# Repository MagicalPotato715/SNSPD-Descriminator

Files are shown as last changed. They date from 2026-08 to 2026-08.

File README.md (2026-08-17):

IMPORTANT INFO:
-
- CTD is the Constant Threshold Discriminator, and contains two amplifiers and one comparator.
- Compute contains a Teensy 4.1 MCU (for counting and general control purposes) and DAC60501MDGSR DAC for CTD reference voltage.
- The single board with both CTD and compute, while possible to manufacture, is not recommended due to general price spiking over 10x10cm
- There may be slight physical mismatches between corresponding parts on CTD/compute and the single board.
- PCBA Essentials should be enough for ordering PCBA; the BOM sources from Mouser; however, most, if not all, components can be found on Digikey.
- When ordering PCBA for the compute board, make sure to separately order Teensy 4.1 boards with header pins already attached (or attach them yourself).
- 

Logistics:
- 
- ***Compute DAC may not Function Correctly***: In this case, J8 (bottom left corner) is hardware controlled through a voltage divider and the 200 ohm trim.
- ***Scalability***: Although the current compute board only features 6 JST conns, the Teensy 4.1 allows this to be expandable to ~30.
- ***CTD Hardware Troubleshooting***: The two LEDs should both light if both 3.3v and 5v respectively, are active. The test points can be used to troubleshoot signals.
- ***Ratbites on Single Board Not Snapping***: There is a chance for the ratbites to not work; the board still functions without the connection severed.
- ***Simulation***: The SPICE models in the single board folder should be enough to simulate; the models may be slightly outdated, look in "Misc files" if needed.
- ***Required Electronics***: The CTD requires a biased SNSPD pulse input via the correct coaxial cable; CTD and compute need to be connected by a 1x5 male-male JST wire with 2.5mm pitch; the compute board requires an external stable 5v source via coaxial cable; the CTD cannot function without 5v coaxial cable power.

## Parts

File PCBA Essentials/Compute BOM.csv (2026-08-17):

Reference | Qty | Value | Footprint | Manufacturer | MPN | Mouser PN | Datasheet
A1 | 2 | Conn_01x24_Socket | Connector_PinSocket_2.54mm:PinSocket_1x24_P2.54mm_Vertical | Samtec | SSQ-124-01-G-S | 200-SSQ12401GS | https://www.sullinscorp.com/
C16,C18,C20 | 3 | 0.1uf | Capacitor_SMD:C_0603_1608Metric | Samsung Electro-Mechanics | CL10B104KB8NNNC | 187-CL10B104KB8NNNC | ~
C17,C19 | 2 | 1uf | Capacitor_SMD:C_0603_1608Metric | Samsung Electro-Mechanics | CL10A105KO8NNNC | 187-CL10A105KO8NNNC | ~
D_1,D_2,D_3,D_4,D_5,D_6 | 6 | LED | LED_SMD:LED_0603_1608Metric | Lite-On | LTST-C190KRKT | LTST-C190KRKT | ~
J2,J4,J5,J6,J7,J8 | 6 | Conn_01x05_Socket | Connector_JST:JST_XH_B5B-XH-A_1x05_P2.50mm_Vertical | JST | B5B-XH-A | 306-B5B-XH-A-GU | ~
J_Power1 | 1 | Conn_Coaxial | Connector_Coaxial:SMA_Samtec_SMA-J-P-H-ST-EM1_EdgeMount | Samtec | SMA-J-P-H-ST-EM1 | SMA-J-P-H-ST-EM1 | ~
R3,R13,R14 | 3 | 1k | Resistor_SMD:R_0603_1608Metric | Yageo | RC0603FR-071KL | 603-RC0603FR-071KL | ~
R4 | 1 | 4.7k | Resistor_SMD:R_0603_1608Metric | Yageo | RC0603FR-074K7L | RC0603FR-074K7L | ~
R5 | 1 | 5.6k | Resistor_SMD:R_0603_1608Metric | Yageo | RC0603FR-075K6L | 603-RC0603FR-075K6L | ~
R7,R8,R9,R10,R11,R12 | 6 | 2k | Resistor_SMD:R_0603_1608Metric | Yageo | RC0603FR-072KL | RC0603FR-072KL | ~
3386F-1-201LF | 1 | 200ohms | Potentiometer_THT:Potentiometer_Runtron_RM-065_Vertical | Bourns | 3386F-1-201LF | 3386F-1-201LF | ~
U5 | 1 | DAC60501ZDGSR | DAC60501ZDGSR:DGS10_TEX | Texas Instruments | DAC60501ZDGSR | 595-DAC60501ZDGSR | https://www.ti.com/lit/gpn/dac60501

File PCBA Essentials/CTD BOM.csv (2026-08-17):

Reference | Qty | Value | Footprint | Manufacturer | MPN | Mouser PN | Datasheet
U_Comparator1 | 1 | LTC6752HSC6-1#TRPBF | Package_TO_SOT_SMD:SOT-363_SC-70-6 | Analog Devices | LTC6752HSC6-1#TRPBF | LTC6752HSC6-1#TRMPBF | https://www.analog.com/media/en/technical-documentation/data-sheets/6752fc.pdf
U2 | 1 | PGA-103+ | Package_TO_SOT_SMD:SOT-89-3 | Mini-Circuits | PGA-103+ | 512-PGA-103+ | https://www.minicircuits.com/pdfs/PGA-103+.pdf
U1 | 1 | PSA4-5043+ | PSA4-5043+:MMM1362_MNC | Mini-Circuits | PSA4-5043+ | 712-PSA4-5043+ | https://www.minicircuits.com/pdfs/PSA4-5043+.pdf
R_Hyst1 | 1 | 80k | Resistor_SMD:R_0603_1608Metric | Yageo | RC0603FR-0780KL | 603-RC0603FR-0780KL | ~
R_b1 | 1 | 1k | Resistor_SMD:R_0603_1608Metric | Yageo | RC0603FR-071KL | 603-RC0603FR-071KL | ~
R_a1 | 1 | 5.6k | Resistor_SMD:R_0603_1608Metric | Yageo | RC0603FR-075K6L | 603-RC0603FR-075K6L | ~
Rterm1,R_s1 | 2 | 50 | Resistor_SMD:R_0402_1005Metric | Yageo | RC0402FR-0750RL | 603-RC0402FR-0750RL | ~
R1 | 1 | 150 | Resistor_SMD:R_0603_1608Metric | Yageo | RC0603FR-07150RL | 603-RC0603FR-07150RL | ~
R2 | 1 | 2k | Resistor_SMD:R_0603_1608Metric | Yageo | RC0603FR-072KL | RC0603FR-072KL | ~
R6 | 1 | 4.7k | Resistor_SMD:R_0603_1608Metric | Yageo | RC0603FR-074K7L | RC0603FR-074K7L | ~
L2 | 1 | 620nH | Inductor_SMD:L_0603_1608Metric | Murata | LQW18AN62NJ00D | 81-LQW18AN62NJ00D | ~
L1,L3 | 2 | 100nh | TCCH+:GU1604_MNC | Mini-Circuits | TCCH-80+ | 139-TCCH-80 | https://www.minicircuits.com/pdfs/TCCH-80+.pdf
J3 | 1 | Conn_Coaxial | Connector_Coaxial:SMA_Samtec_SMA-J-P-H-ST-EM1_EdgeMount | Samtec | SMA-J-P-H-ST-EM1 | 713-SMA-J-P-H-ST-EM1 | ~
C13,C15 | 2 | 1uf | Capacitor_SMD:C_0603_1608Metric | Samsung Electro-Mechanics | CL10A105KO8NNNC | 187-CL10A105KO8NNNC | ~
C10 | 1 | 0.33uf | Capacitor_SMD:C_0603_1608Metric | Yageo | CC0603KRX7R9BB334 | 603-CC0603KRX7R9BB334 | ~
C9 | 1 | 330pf | Capacitor_SMD:C_0402_1005Metric | Samsung Electro-Mechanics | CL05C331JB5NNNC | 187-CL05C331JB5NNNC | ~
C7 | 1 | 330pf | Capacitor_SMD:C_0603_1608Metric | Samsung Electro-Mechanics | CL10C331JB8NNNC | 187-CL10C331JB8NNNC | ~
C6,C11 | 2 | 10uf | Capacitor_SMD:C_0805_2012Metric | Samsung Electro-Mechanics | CL21A106KOQNNNG | 187-CL21A106KAQNNNE | ~
C5,C12,C14 | 3 | 0.1uf | Capacitor_SMD:C_0603_1608Metric | Samsung Electro-Mechanics | CL10B104KB8NNNC | 187-CL10B104KB8NNNC | ~
C3 | 1 | 100pf | Capacitor_SMD:C_0402_1005Metric | Samsung Electro-Mechanics | CL05C101JB5NNNC | 187-CL05C101JB5NNNC | ~
C1,C2,C4,C8 | 4 | 0.01uf | Capacitor_SMD:C_0402_1005Metric | Samsung Electro-Mechanics | CL05B103KB5NNNC | 187-CL05B103KB5NNNC | ~
J1 | 1 | Conn_01x05_Socket | Connector_JST:JST_XH_B5B-XH-A_1x05_P2.50mm_Vertical | JST | B5B-XH-A | 306-B5B-XH-A-GU | ~
D_Life3.3, D_Life5 | 2 | LED | LED_SMD:LED_0603_1608Metric | Lite-On | LTST-C190KRKT | LTST-C190KRKT | ~

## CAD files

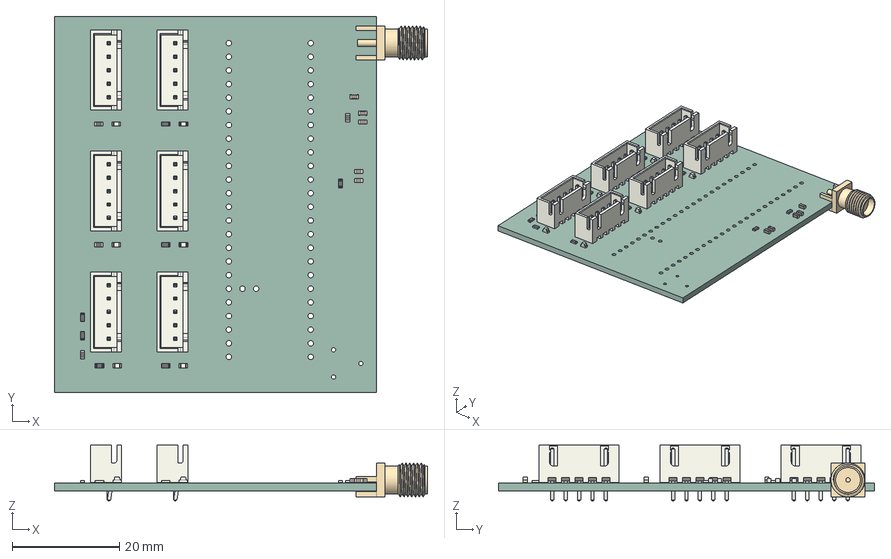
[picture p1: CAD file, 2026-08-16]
Compute/Misc Files/3D Model.step
69.5 x 70.0 x 10.4 mm
JST_XH_B5B-XH-A_1x05_P2.50mm_Vertical x 6
C_0603_1608Metric x 5
R_0603_1608Metric x 11
SMA_Samtec_SMA-J-P-H-ST-EM1_EdgeMount
LED_0603_1608Metric x 6
Discriminator_PCB

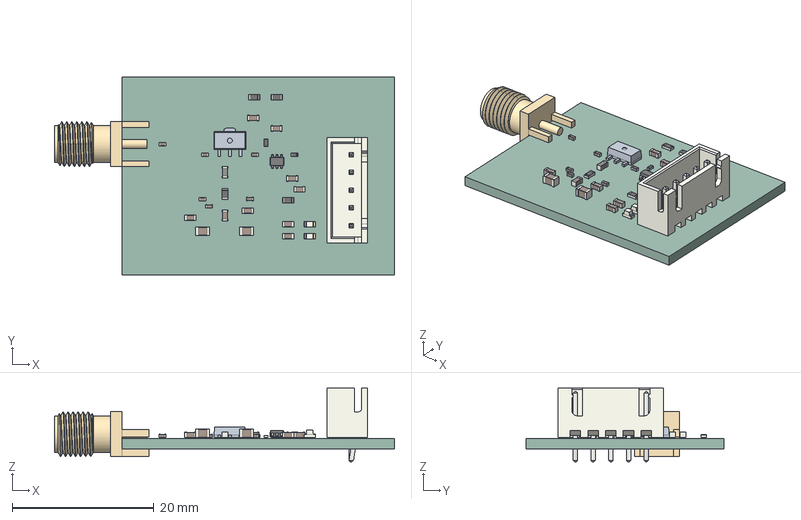
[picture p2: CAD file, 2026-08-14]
CTD/Misc Files/3D Model.step
48.0 x 28.0 x 10.4 mm
L_0603_1608Metric
3D Model 1.2.1
C_0402_1005Metric x 6
C_0603_1608Metric x 9
C_0805_2012Metric x 2
R_0603_1608Metric x 4
SOT-363_SC-70-6
LED_0603_1608Metric x 2
JST_XH_B5B-XH-A_1x05_P2.50mm_Vertical
R_0402_1005Metric x 2
SMA_Samtec_SMA-J-P-H-ST-EM1_EdgeMount
Discriminator_PCB

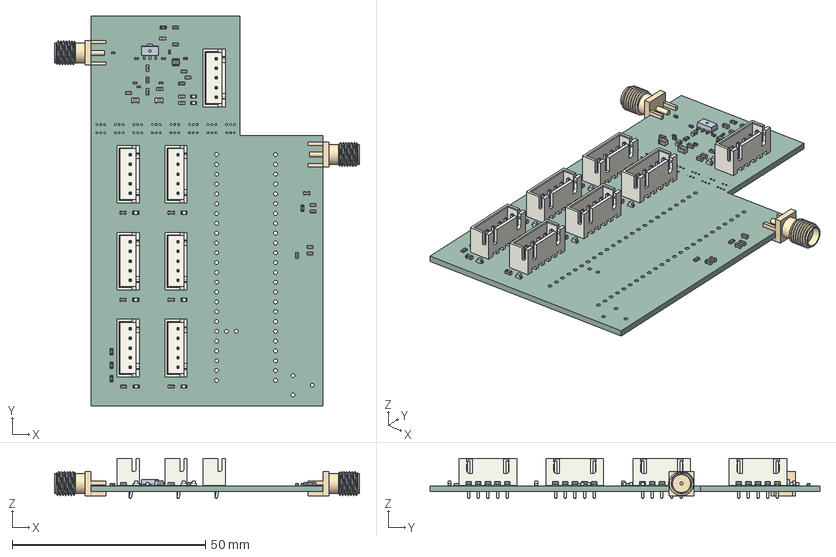
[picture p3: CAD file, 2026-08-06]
Single-Board/Misc Files/3D Model.step
79.0 x 100.9 x 10.4 mm
L_0603_1608Metric
JST_XH_B5B-XH-A_1x05_P2.50mm_Vertical x 7
C_0603_1608Metric x 20
3D Model 1.4.1
C_0402_1005Metric x 6
C_0805_2012Metric x 2
R_0603_1608Metric x 9
SOT-363_SC-70-6
SMA_Samtec_SMA-J-P-H-ST-EM1_EdgeMount x 2
LED_0603_1608Metric x 8
R_0402_1005Metric x 2
Discriminator_PCB

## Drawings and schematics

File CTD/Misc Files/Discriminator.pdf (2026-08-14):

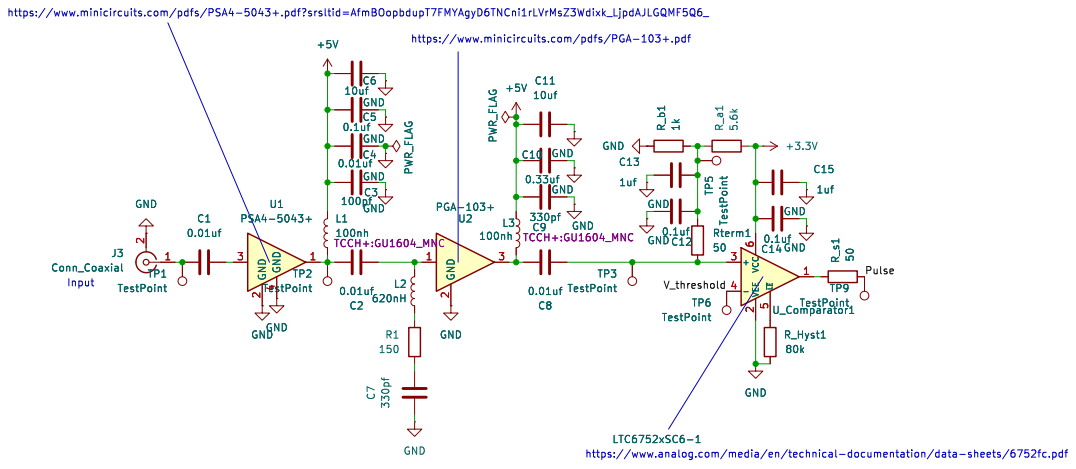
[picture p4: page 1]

https://www.minicircuits.com/pdfs/PSA4-5043+.pdf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

https://www.minicircuits.com/pdfs/PGA-103+.pdf
0.1ufGND GND

LTC6752xSC6-1
https://www.analog.com/media/en/technical-documentation/data-sheets/6752fc.pdf

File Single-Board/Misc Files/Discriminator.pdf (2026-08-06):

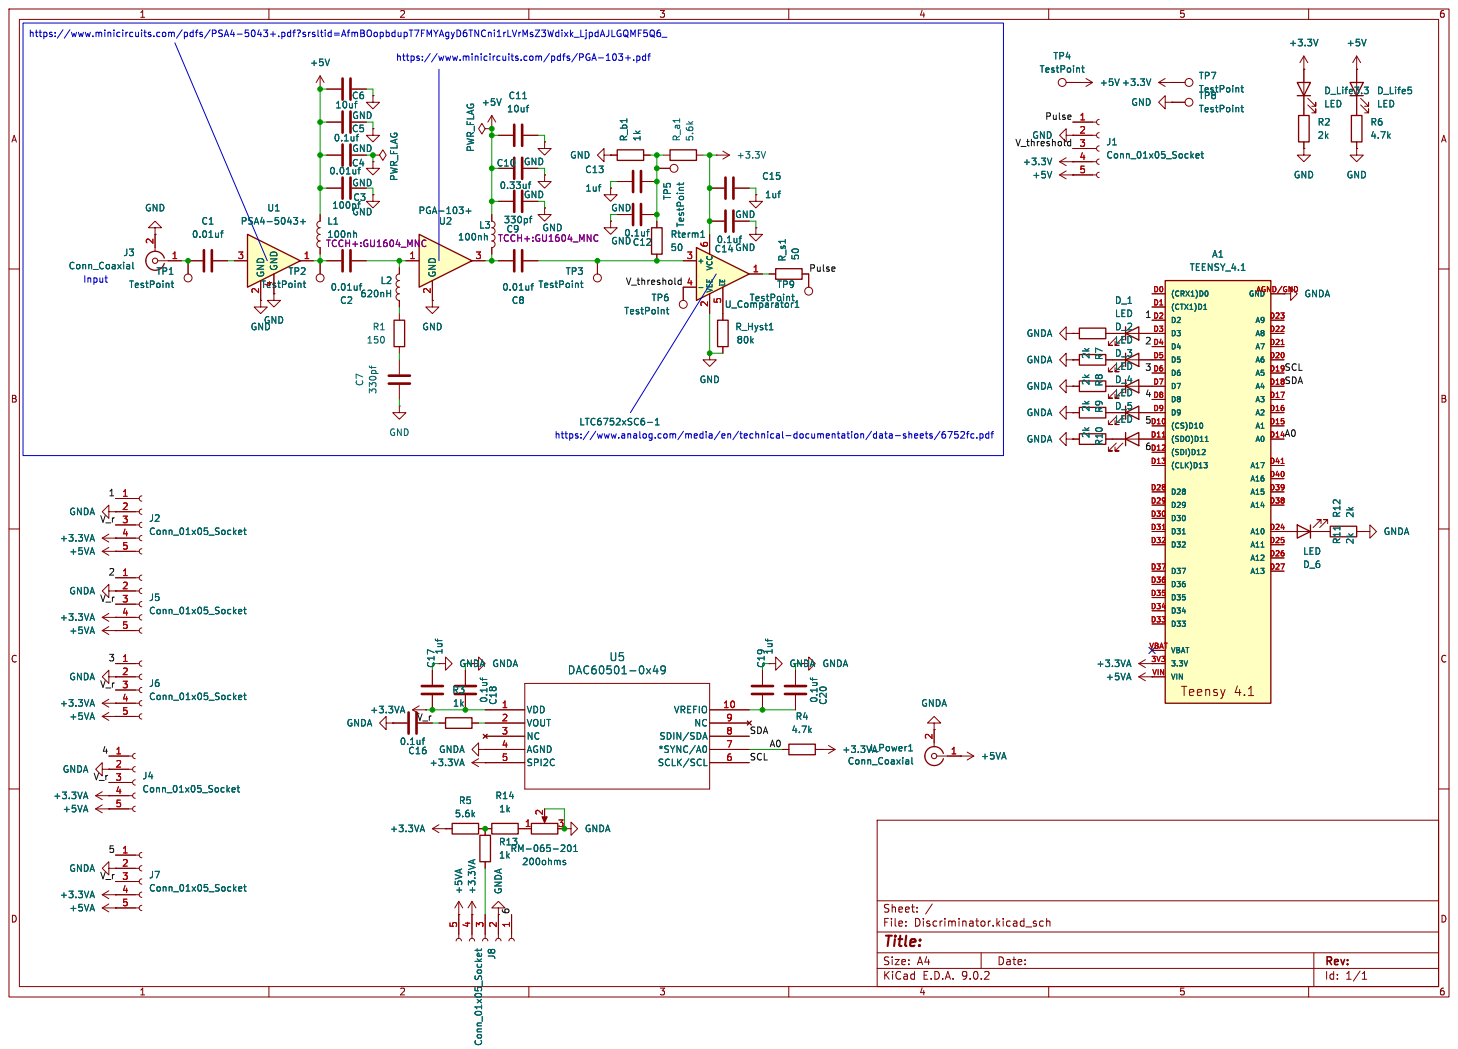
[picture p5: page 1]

https://www.minicircuits.com/pdfs/PSA4-5043+.pdf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

https://www.minicircuits.com/pdfs/PGA-103+.pdf
0.1uf GNDA

LTC6752xSC6-1
https://www.analog.com/media/en/technical-documentation/data-sheets/6752fc.pdf

Id: 1/1 Title: File: Discriminator.kicad_sch Sheet: /

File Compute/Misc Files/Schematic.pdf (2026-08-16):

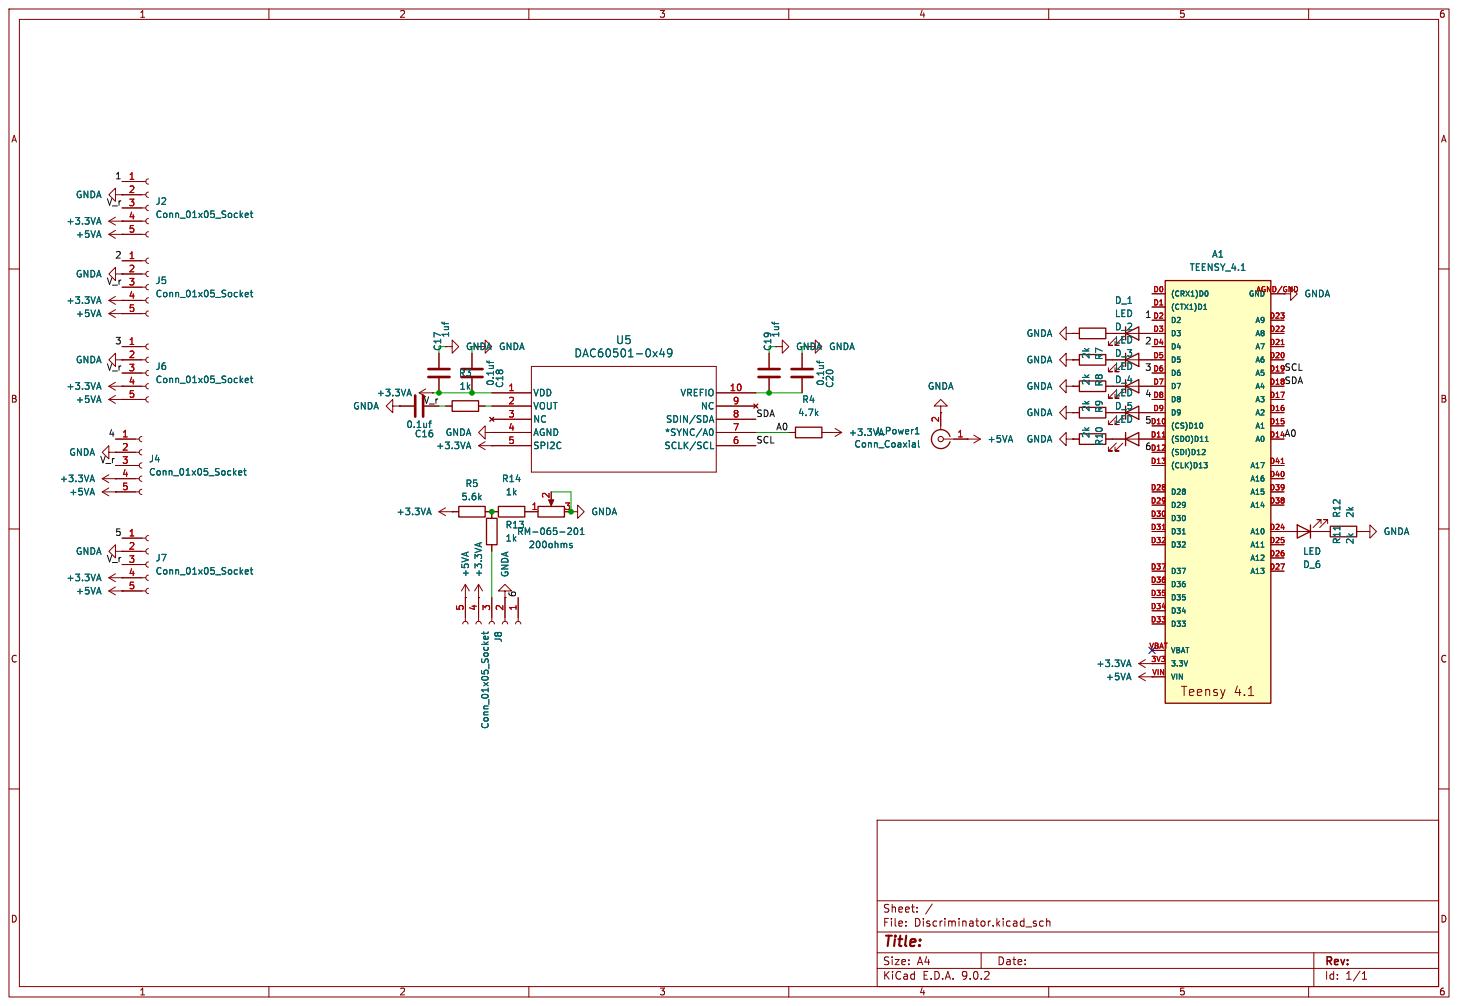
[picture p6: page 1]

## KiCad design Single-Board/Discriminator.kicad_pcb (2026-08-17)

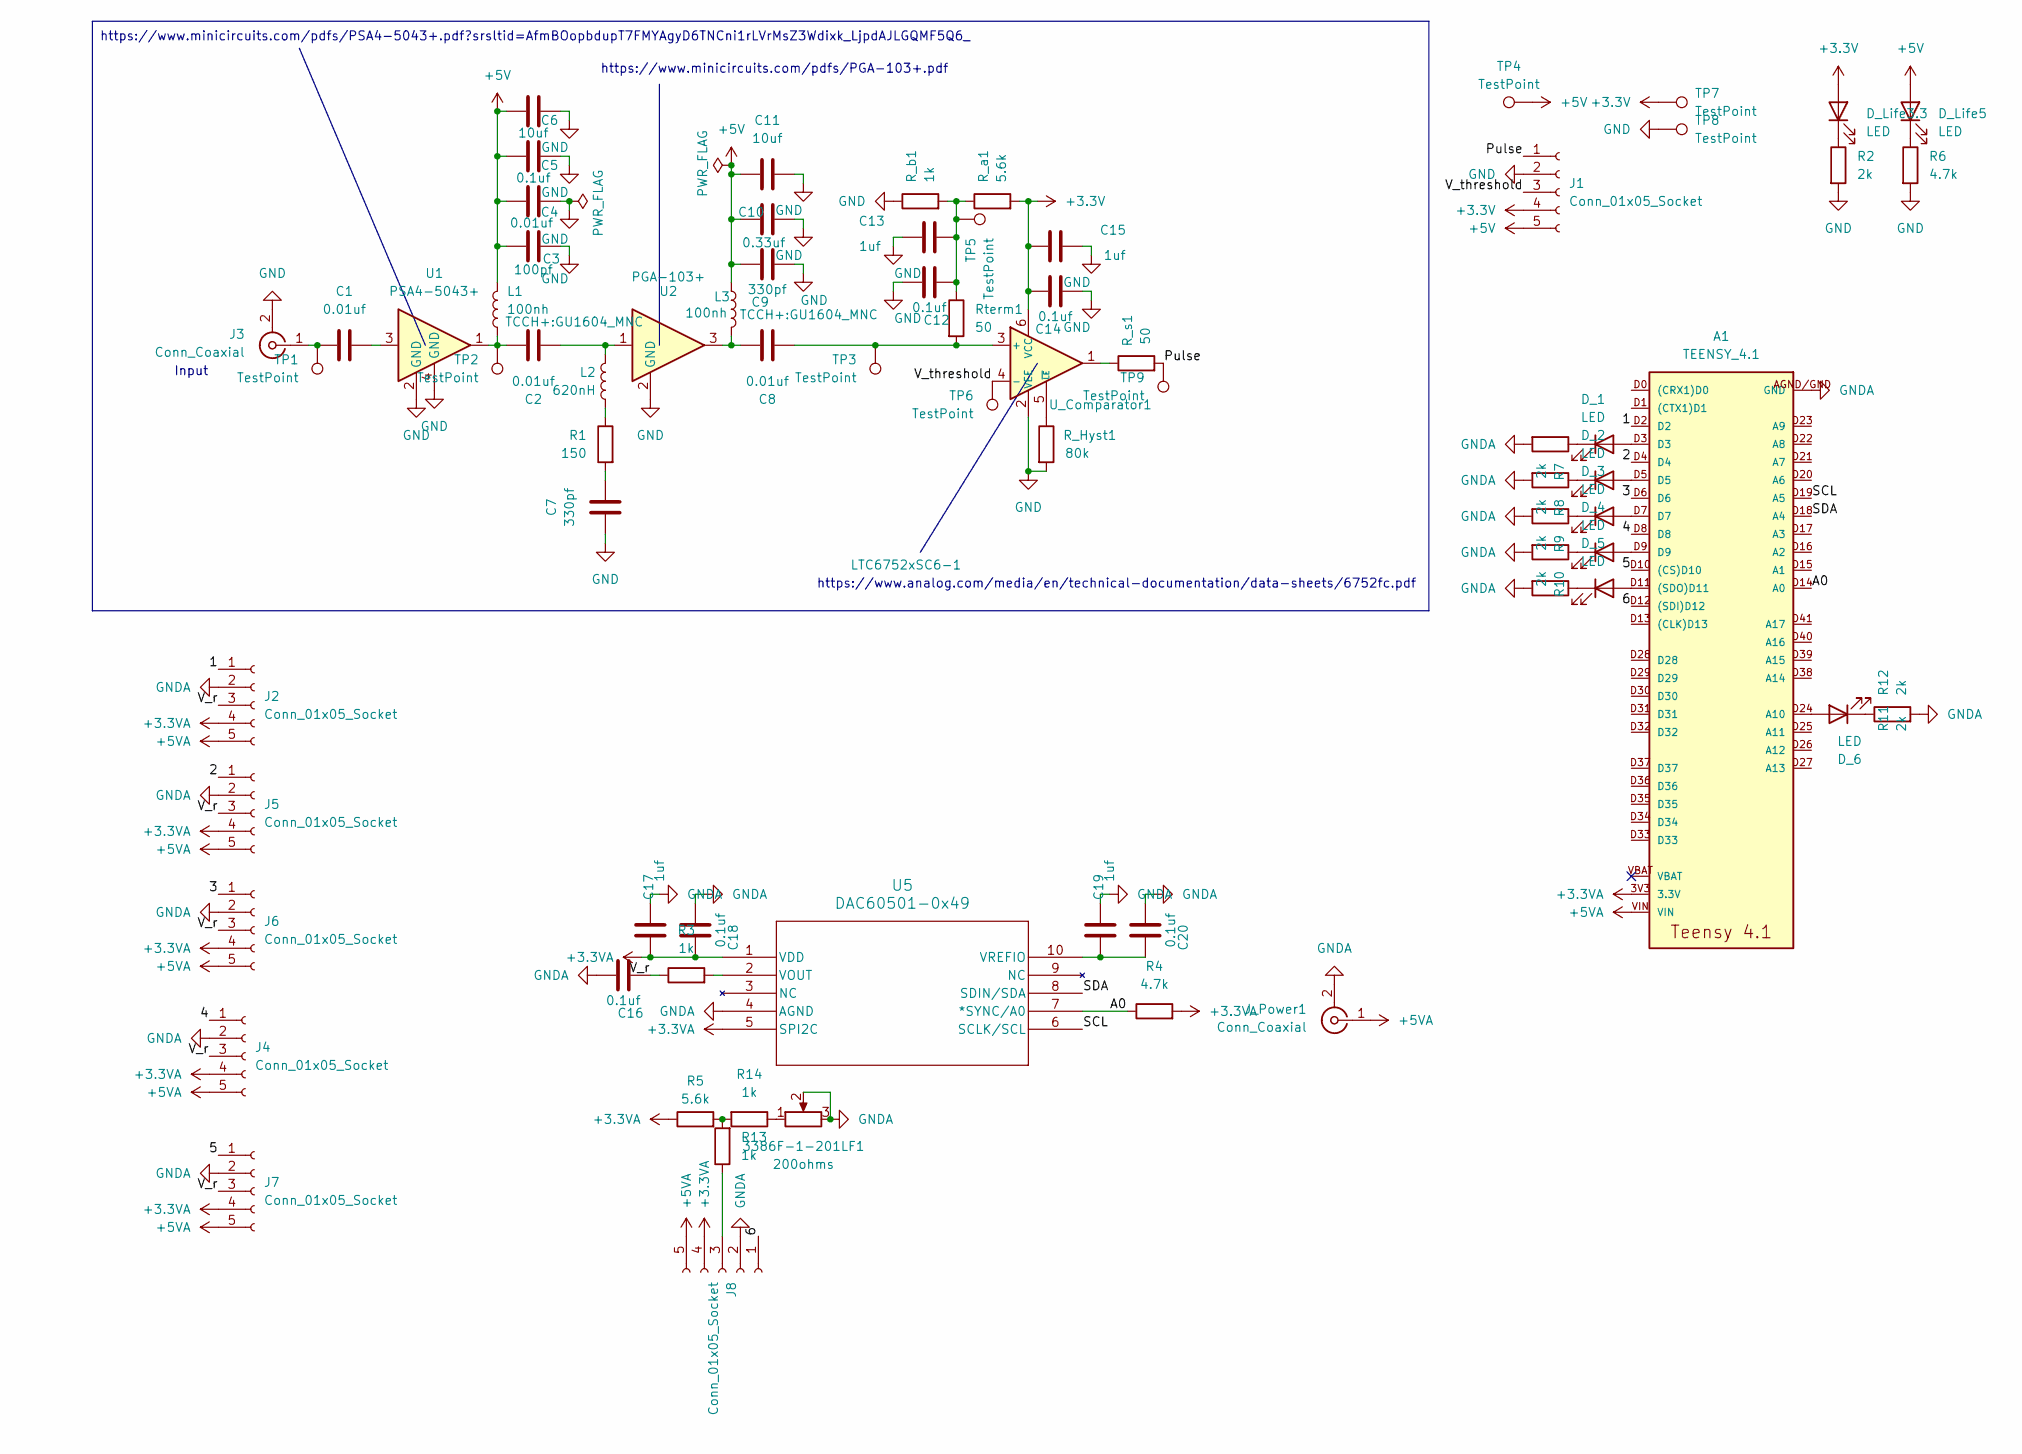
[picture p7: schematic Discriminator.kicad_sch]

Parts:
3386F-1-201LF1: 200ohms; Potentiometer_Bourns_3386F_Vertical
A1: TEENSY_4.1; TEENSY_LONG_EXT
C1, C2, C4, C8: 0.01uf; C_0402_1005Metric
C3: 100pf; C_0402_1005Metric
C5, C12, C14, C16, C18, C20: 0.1uf; C_0603_1608Metric
C6, C11: 10uf; C_0805_2012Metric
C7: 330pf; C_0603_1608Metric
C9: 330pf; C_0402_1005Metric
C10: 0.33uf; C_0603_1608Metric
C13, C15, C17, C19: 1uf; C_0603_1608Metric
D_1, D_2, D_3, D_4, D_5, D_6: LED; LED_0603_1608Metric
D_Life3.3, D_Life5: LED; LED_0603_1608Metric
J1, J2, J4, J5, J6, J7, J8: Conn_01x05_Socket; JST_XH_B5B-XH-A_1x05_P2.50mm_Vertical
J3: Conn_Coaxial; SMA_Samtec_SMA-J-P-H-ST-EM1_EdgeMount
J_Power1: Conn_Coaxial; SMA_Samtec_SMA-J-P-H-ST-EM1_EdgeMount
L1, L3: 100nh; GU1604_MNC
L2: 620nH; L_0603_1608Metric
R1: 150; R_0603_1608Metric
R2, R7, R8, R9, R10, R11, R12: 2k; R_0603_1608Metric
R3, R13, R14: 1k; R_0603_1608Metric
R4, R6: 4.7k; R_0603_1608Metric
R5: 5.6k; R_0603_1608Metric
R_Hyst1: 80k; R_0603_1608Metric
R_a1: 5.6k; R_0603_1608Metric
R_b1: 1k; R_0603_1608Metric
R_s1: 50; R_0402_1005Metric
Rterm1: 50; R_0402_1005Metric
TP1, TP2, TP3, TP4, TP5, TP6, TP7, TP8, TP9: TestPoint; TestPoint_Pad_1.0x1.0mm
U1: PSA4-5043+; MMM1362_MNC
U2: PGA-103+; SOT-89-3
U5: DAC60501-0x49; DGS10_TEX
U_Comparator1: LTC6752xSC6-1; SOT-363_SC-70-6

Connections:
+3.3V: C14.1, C15.1, D_Life3.3.2 (A), J1.4, R_a1.2, TP7.1, U_Comparator1.6 (VCC)
+3.3VA: A1.3V3 (3.3V), A1.3V3@2 (3.3V), A1.3V3@3 (3.3V), C17.1, C18.1, J2.4, J4.4, J5.4, J6.4, J7.4, J8.4, R4.2, R5.1, U5.1 (VDD), U5.5 (SPI2C)
+5V: C3.1, C4.1, C5.1, C6.1, C9.1, C10.1, C11.1, D_Life5.2 (A), J1.5, L1.3, L3.3, TP4.1
+5VA: A1.VIN, J2.5, J4.5, J5.5, J6.5, J7.5, J8.5, J_Power1.1 (In)
/1: A1.D2, J2.1
/2: A1.D4, J5.1
/3: A1.D6, J6.1
/4: A1.D8, J4.1
/5: A1.D10 ((CS)D10), J7.1
/6: A1.D12 ((SDI)D12), J8.1
/A0: A1.D14 (A0), R4.1, U5.7 (*SYNC/A0)
/Pulse: J1.1, R_s1.2, TP9.1
/SCL: A1.D19 (A5), U5.6 (SCLK/SCL)
/SDA: A1.D18 (A4), U5.8 (SDIN/SDA)
/V_r: C16.1, J2.3, J4.3, J5.3, J6.3, J7.3, R3.1
/V_threshold: J1.3, TP6.1, U_Comparator1.4 (-)
GND: C3.2, C4.2, C5.2, C6.2, C7.2, C9.2, C10.2, C11.2, C12.2, C13.2, C14.2, C15.2, J1.2, J3.2 (Ext), R2.2, R6.2, R_Hyst1.2, R_b1.1, TP8.1, U1.2 (GND), U1.4 (GND), U2.2 (GND), U_Comparator1.2 (VEE)
GNDA: 3386F-1-201LF1.2, 3386F-1-201LF1.3, A1.AGND/GND (GND), A1.GND, A1.GND@2 (GND), C16.2, C17.2, C18.2, C19.2, C20.2, J2.2, J4.2, J5.2, J6.2, J7.2, J8.2, J_Power1.2 (Ext), R7.2, R8.2, R9.2, R10.2, R11.2, R12.2, U5.4 (AGND)
unnamed: 3386F-1-201LF1.1, R14.1
unnamed: A1.D11 ((SDO)D11), D_5.2 (A)
unnamed: A1.D24 (A10), D_6.2 (A)
unnamed: C1.1, U1.3
unnamed: C2.1, L2.1, U2.1
unnamed: C2.2, L1.1, TP2.1, U1.1
unnamed: C7.1, R1.2
unnamed: C8.1, L3.1, U2.3
unnamed: C12.1, C13.1, R_a1.1, R_b1.2, Rterm1.1, TP5.1
unnamed: A1.D3, D_1.2 (A)
unnamed: D_1.1 (K), R7.1
unnamed: A1.D5, D_2.2 (A)
unnamed: D_2.1 (K), R8.1
unnamed: A1.D7, D_3.2 (A)
unnamed: D_3.1 (K), R9.1
unnamed: A1.D9, D_4.2 (A)
unnamed: D_4.1 (K), R10.1
unnamed: D_5.1 (K), R11.1
unnamed: D_6.1 (K), R12.1
unnamed: D_Life3.3.1 (K), R2.1
unnamed: D_Life5.1 (K), R6.1
unnamed: C1.2, J3.1 (In), TP1.1
unnamed: J8.3, R13.1
unnamed: L2.2, R1.1
unnamed: R5.2, R13.2, R14.2
unnamed: R_s1.1, U_Comparator1.1
unnamed: R3.2, U5.2 (VOUT)
unnamed: C19.1, C20.1, U5.10 (VREFIO)
unnamed: C8.2, Rterm1.2, TP3.1, U_Comparator1.3 (+)
unnamed: R_Hyst1.1, U_Comparator1.5 (~LE)

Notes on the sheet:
https://www.minicircuits.com/pdfs/PSA4-5043+.pdf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
Input
https://www.minicircuits.com/pdfs/PGA-103+.pdf
https://www.analog.com/media/en/technical-documentation/data-sheets/6752fc.pdf

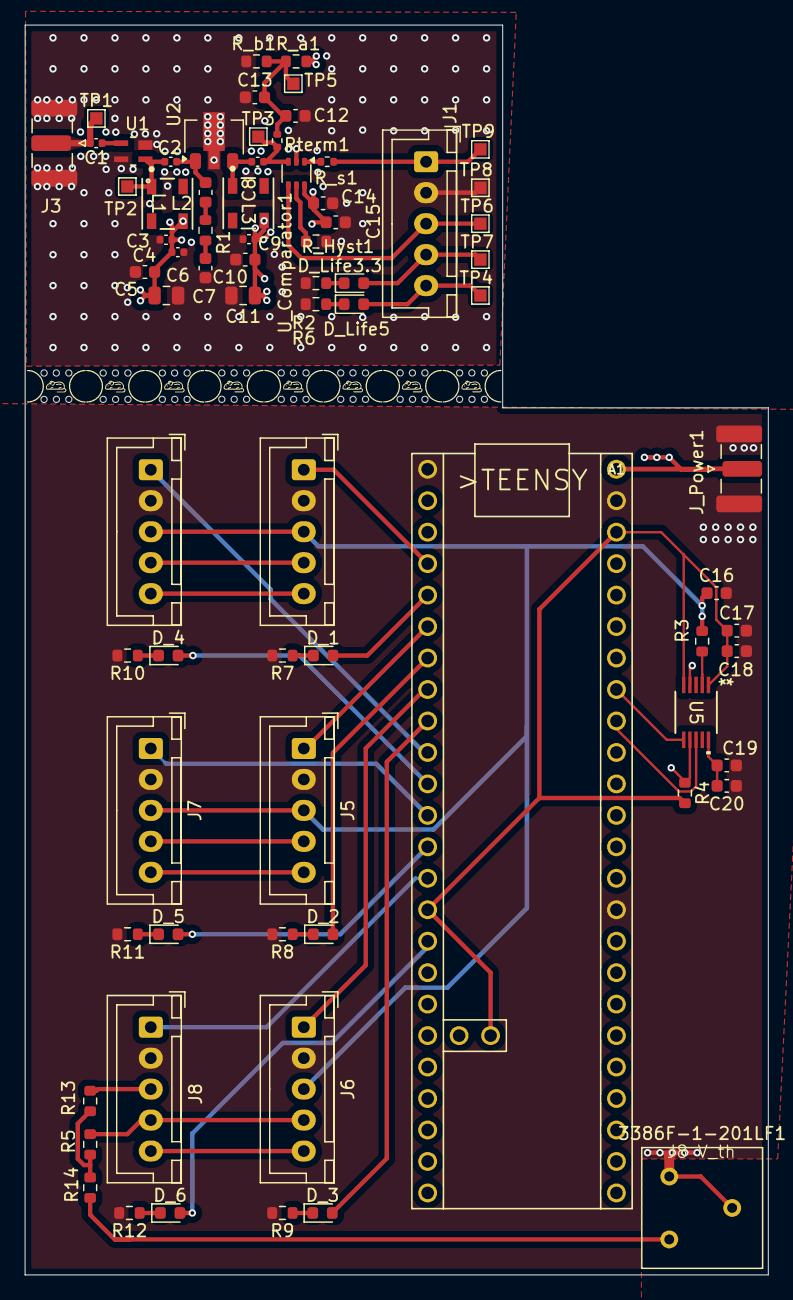
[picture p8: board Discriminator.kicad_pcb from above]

Board: 4 copper layers, 60.0 x 100.9 mm, 82 parts (0 on the bottom side), 48 nets.

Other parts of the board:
mouse-bite-2.54mm-4.66mm, mouse-bite-2.54mm-4.66mm#2, mouse-bite-2.54mm-4.66mm#3, mouse-bite-2.54mm-4.66mm#4, mouse-bite-2.54mm-4.66mm#5, mouse-bite-2.54mm-4.66mm#6, mouse-bite-2.54mm-4.66mm#7, mouse-bite-2.54mm-4.66mm#8: VAL**; mouse-bite-2.54mm-4.66mm

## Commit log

2026-07-24 added fab_files: gerber & drill
    [Discriminator-B_Cu.gbr, Discriminator-B_Mask.gbr, Discriminator-B_Paste.gbr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]
2026-07-29 added mcu section, added test points to CTD
    [Discriminator-B_Cu.gbr, Discriminator-B_Mask.gbr, Discriminator-B_Paste.gbr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]
2026-08-06 Misc changes
    [3D Model.step, BOM.csv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]
2026-08-14 separate CTD & compute. Add CTD BOM
    [3D Model.step, CTD BOM.csv, CTD.kicad_sch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]
2026-08-16 Complete separation of CTD & Compute, completed Compute BOM, fixed issues
    [3D Model.step, Compute BOM.csv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]
2026-08-17 tweaks and bug fixes
    [BOM.csv, CTD BOM.csv, Compute BOM.csv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]
2026-08-17 add essentials folder for easy access
    [CTD BOM.csv, Compute BOM.csv]
2026-08-17 Add important info and logistics to README
    Added important information and logistics regarding the CTD and compute board, including hardware requirements and troubleshooting tips.
